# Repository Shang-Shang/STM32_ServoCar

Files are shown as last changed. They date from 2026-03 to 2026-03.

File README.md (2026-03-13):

---

# STM32_ServoCar：基于STM32与ELRS协议的智能遥控小车

<div align="center">

舵机小车-成品方案

**全流程自主开发的智能遥控小车｜从电路仿真到机械结构设计的一体化实践**



[]()

</div>

## 📋 项目概述

本项目是一个完全自主开发的智能遥控小车，旨在通过完整的硬件产品开发流程，系统性地实践嵌入式系统、电路设计和机械结构相关知识。

### 核心参数
- **主控芯片**：STM32F103C8T6
- **通信协议**：ELRS（ExpressLRS）2.4G，实现高响应遥控
- **硬件设计**：Proteus仿真验证 → Cadence/立创EDA绘制原理图与PCB → 嘉立创打样生产
- **结构设计**：SolidWorks完成整车三维建模与结构优化

### ✨ 项目亮点
- ✅ **全流程自主开发**：从电路仿真、嵌入式开发到机械结构设计，实现产品完整研发流程
- ✅ **双版本迭代优化**：V1立创EDA入门验证 → V2 Cadence专业设计，形成清晰的迭代改进路径
- ✅ **完整的文档体系**：包含采购清单、电路原理图、PCB设计文件、3D模型及源码

---

## 🔄 版本演进

本项目经历了两个主要版本的迭代：

<div align="center">
实物照片
<p><em>实物照片：第一版PCB兼容两代车架</em></p>
</div>

### 第一版：麦轮小车
- 采用四个N20减速电机，通过差速控制实现全向移动
- 使用立创EDA完成PCB设计（适合初学者快速上手）
- 验证了ELRS通信协议和基础运动控制逻辑

### 第二版：舵机转向小车
- 保留第一版PCB的兼容性，仅更换车架结构
- 采用SG90舵机实现前轮转向 + 后轮驱动
- 使用Cadence重新设计PCB，优化布局和电源保护
- SolidWorks完成整车结构优化，3D打印制作车架

---

## 📦 采购清单

| 组件 | 规格/型号 | 数量 | 备注 |
|---|---|---|---|
| ELRS接收机 | 2.4G 100mW | 1 | 串口通信 |
| 锂电池 | 7.4V 2S | 1 | 供电推荐 |
| N20减速电机 | 6V 200RPM（推荐） | 4 | 4电机驱动 |
| 轮胎 | 14mm橡胶胎 | 4 | 适配舵机版小车 |
| SG90舵机 | 9g微型舵机 | 1 | 转向机构 |
| 螺丝 | M3*10 | 若干 | 固定结构件 |
| PCB板 | 定制 | 1 | BOM表详见下方 |

> 📌 完整BOM表可在`00_BOM`文件夹中下载

---

## 💻 嵌入式开发

### 开发环境
- **IDE**：STM32CubeIDE（HAL库）
- **调试工具**：ST-Link

<div align="center">
CubeIDE配置
<p><em>STM32CubeIDE引脚功能配置</em></p>
</div>

### 代码结构

#### 舵机与电机控制 (`sk_motor.c`)
```c
void Servo_Init(void);           // 舵机初始化（PWM配置）
void Servo_Move(uint8_t CHn);    // 舵机转向控制，输入0~100（对应-90°~+90°）
void Motor_Init(void);            // 电机驱动初始化（GPIO+PWM）
void Motor_Move(uint8_t CHn, uint8_t Start);  // 电机调速，输入0~100
```

#### ELRS协议解析 (`elrs.c`)
```c
uint16_t ELRS_CRC8(uint8_t *Data);                // CRC校验（多项式0xD5，初始值0x00）
void ELRS_DataAnalysis(uint16_t *Channel, uint8_t *ReceiveData);  // 解析ELRS负载数据，提取CH1~CH10
uint16_t ELRS_ToPercentage(uint16_t CHn, uint16_t Min, uint16_t Max);  // 通道值归一化（0~100）
void ELRS_Process(uint8_t *DataA, uint8_t *CH);   // 主处理函数：原始数据输入→CH1~CH10输出（0~100）
```

<div align="center">
代码结构
<p><em>详细代码查看如上目录</em></p>
</div>

### 📡 ELRS通信协议详解

**串口配置**：
- USART1（PA9-TX, PA10-RX）
- 波特率：420Kbits
- 数据格式：8N1
- 供电：5V

**数据包结构**：

| 字节位置 | 内容 | 说明 |
|---|---|---|
| 0 | 同步字节 | 固定为`0xC8` |
| 1 | 长度 | 类型`1`+负载`22`+CRC`1`=`24`（十六进制`0x18`） |
| 2 | 类型 | 表示数据帧的类型，RC通道数据类型为`0x16` |
| 3~24 | 负载 | CH1~CH16，每个通道11bit，共176位（22字节） |
| 25 | CRC校验 | 校验范围：字节2~24 |

> CRC算法：多项式`0xD5`，初始值`0x00`，用于数据完整性验证

### 🔧 Proteus仿真

在PCB打样前，使用Proteus搭建仿真电路，验证STM32最小系统、电机驱动逻辑。

<div align="center">
Proteus仿真
<p><em>Proteus电路仿真验证</em></p>
</div>

---

## 🔌 硬件设计

### 电源功耗预算

| 组件 | 工作电压 | 典型电流 | 峰值电流 | 备注 |
|---|---|---|---|---|
| N20电机（单个） | 6V | 100mA | 200mA | 堵转电流 |
| SG90舵机 | 5V | 200mA | 500mA | 堵转电流 |
| ELRS接收机 | 5V | 20mA | 30mA | - |
| TB6612FNG（双路） | 5V | 5mA | 10mA | 逻辑部分 |
| STM32F103 | 3.3V | 50mA | 150mA | - |
| **总计** | - | **~500mA** | **~1.5A** | 按四个电机 |

### 版本V1：立创EDA入门验证

作为PCB设计的入门实践，第一版采用立创EDA完成，重点掌握原理图绘制、PCB布局布线、BOM导出和样板焊接调试。

#### 关键元件参数

| 参考文档 | 型号 | 封装 | 功能 | 关键参数 |
|-----|---|---|---|---|
| B1 | LDL1117S33R | SOT-223 | 3.3V LDO | 输入2.5-18V，输出3.3V/1.2A，压差350mV@1.2A |
| B2 | LDL1117S50R | SOT-223 | 5V LDO | 输入2.5-18V，输出5V/1.2A，压差600mV@1.2A |
| C3 | TB6612FNG | SSOP-24 | 电机驱动 | 逻辑5V，驱动15Vmax，1.2A(ave)/3.2A(peak) |

#### 设计文件

<div align="center">
V1原理图
<p><em>V1原理图（立创EDA）</em></p>
</div>

<div align="center">
V1 PCB布局
<p><em>V1 PCB布局布线</em></p>
</div>

#### BOM表

<div align="center">
V1 BOM
<p><em>V1 BOM表（可在00_BOM文件夹下载）</em></p>
</div>

#### 实物成品

<div align="center">
V1 PCB成品
<p><em>V1 PCB打样成品</em></p>
</div>

#### 版本V1经验教训

1. **布局不合理**：电机接线端口集中在单侧，导致小车走线混乱，线束整理困难
2. **缺少保护机制**：无过流/过压保护，若电源模块击穿会损坏全板
3. **踩坑教训**：采购廉价芯片导致反复排查，延误开发进度约两周

### 版本V2：Cadence专业设计

基于V1的经验教训，使用Cadence进行完全重新设计，引入更专业的EDA工具链。

#### 工具链学习
- **OrCAD Capture**：原理图设计、元器件符号绘制、网表和BOM导出
- **Padstack Editor**：焊盘和过孔定制
- **Allegro PCB Designer**：PCB布局布线、封装绘制、规则设置

#### 关键改进

1. ✅ **布局优化**：电机输出端口按实际需求调整，便于走线整理
2. ✅ **过流保护**：增加保险丝，防止电源短路损坏
3. ✅ **电源模块重构**：优化电源走线，提升接入电压上限
4. ✅ **电源开关**：增加总电源控制，方便调试

#### 新增关键元件

| 参考文档 | 型号 | 封装 | 功能 | 关键参数 |
|-----|---|---|---|---|
| B3 | MP1584EN-LF-Z | SOIC-8-EP | DCDC降压 | 输入7-28V，输出0.8-25V，3A，静态电流100uA |

#### 原理图设计

<div align="center">
V2原理图1
<p><em>V2原理图 - 设计思路</em></p>
</div>

<div align="center">
V2原理图2
<p><em>V2原理图 - MCU</em></p>
</div>

<div align="center">
V2原理图3
<p><em>V2原理图 - POWER</em></p>
</div>

<div align="center">
V2原理图4
<p><em>V2原理图 - 电机驱动</em></p>
</div>

<div align="center">
V2原理图5
<p><em>V2原理图 - 对外接口</em></p>
</div>

#### PCB设计

<div align="center">
V2 PCB顶层
<p><em>V2 PCB - 顶层布线</em></p>
</div>

<div align="center">
V2 PCB GND层
<p><em>V2 PCB - GND层</em></p>
</div>

<div align="center">
V2 PCB电源层
<p><em>V2 PCB - 电源层</em></p>
</div>

<div align="center">
V2 PCB双层视图
<p><em>V2 PCB - 底层</em></p>
</div>

#### BOM表

<div align="center">
V2 BOM
<p><em>V2 BOM表</em></p>
</div>

---

## 🏗️ 机械结构设计

### SolidWorks 3D建模

使用SolidWorks完成整车结构设计，包括底盘承载布局、舵机安装机构、电池仓设计和螺丝固定位优化。

<div align="center">
SolidWorks模型
<p><em>SolidWorks整车三维模型</em></p>
</div>

### 3D打印实现

从SolidWorks导出STL文件，导入Blender进行模型预览与颜色配置。

<div align="center">
Blender渲染
<p><em>Blender渲染效果图</em></p>
</div>

**打印参数**：
- **设备**：拓竹P1S（0.4mm喷头）
- **材料**：PLA/ PETG

**设计注意事项**：
- 打印误差补偿：PLA/PETG普遍存在0.1~0.2mm误差，设计需预留公差
- 螺丝孔优化：若需拧入M3螺丝，设计孔径**2.95mm**可获得最佳紧固效果

---

## 📚 参考目录

| 编号 | 文档名称 | 说明 |
|-----|---|---|
| 【A1】 | STM32F103x8B数据手册 | 主控芯片数据手册 |
| 【A2】 | STM32F10xxx参考手册 | 开发参考手册 |
| 【A3】 | STM32F103C8T6引脚定义 | 引脚功能定义 |
| 【B1】 | LDL1117S33R规格书 | 3.3V LDO数据手册 |
| 【B2】 | LDL1117S50R规格书 | 5V LDO数据手册 |
| 【B3】 | MP1584EN-LF-Z规格书 | DCDC电源芯片数据手册 |
| 【C3】 | TB6612FNG规格书 | 电机驱动芯片数据手册 |

---

## 📬 联系我

- **邮箱1**：1161812370@qq.com
- **邮箱2**：shang_ah@sina.com

**如果这个项目对你有帮助，欢迎Star⭐！**

---

> **项目状态**：持续完善中

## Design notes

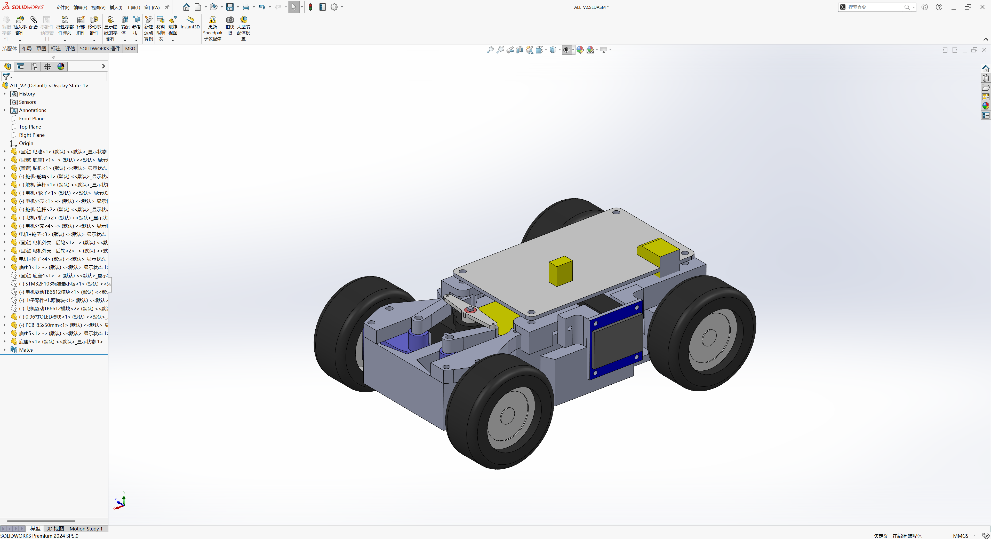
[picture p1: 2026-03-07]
04 Solidworks/舵机小车-成品方案.png

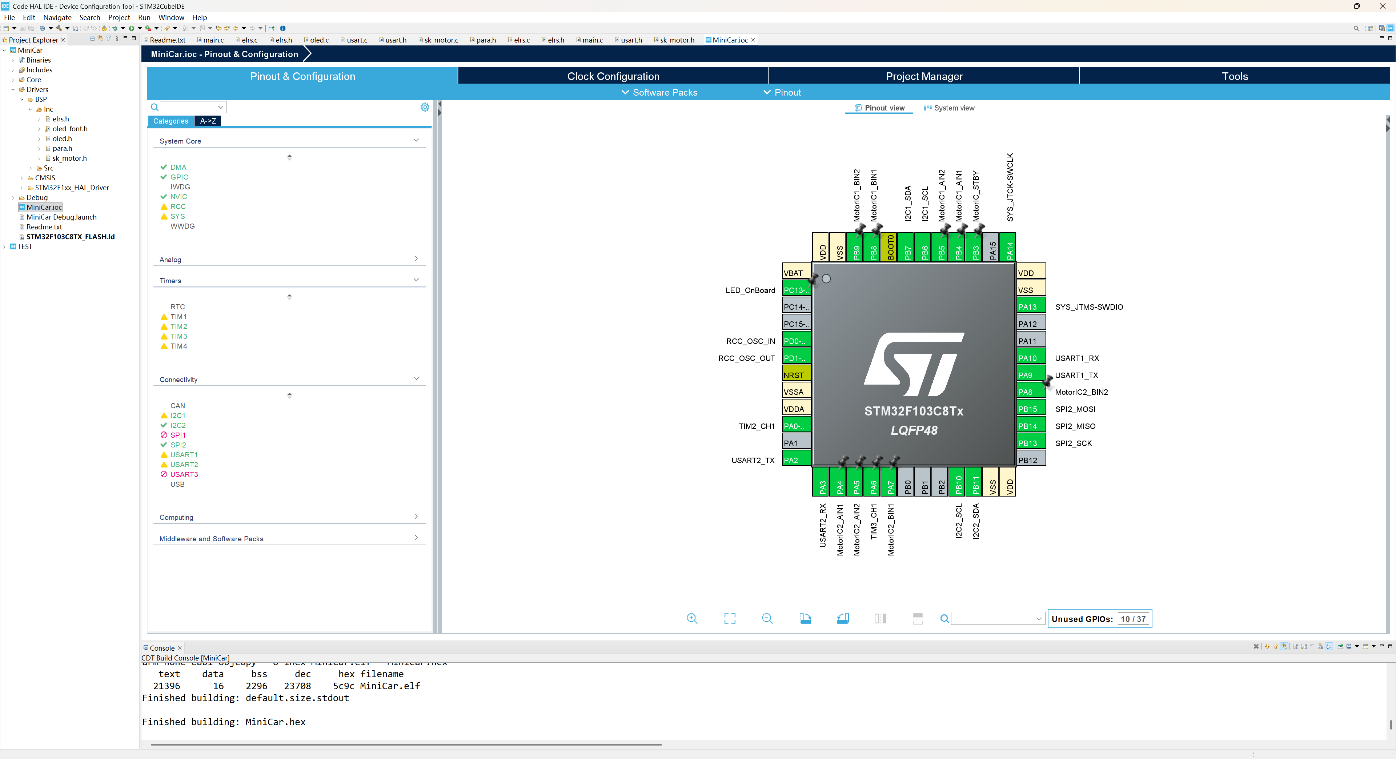
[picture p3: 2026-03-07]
02 HAL IDE/功能配置.png

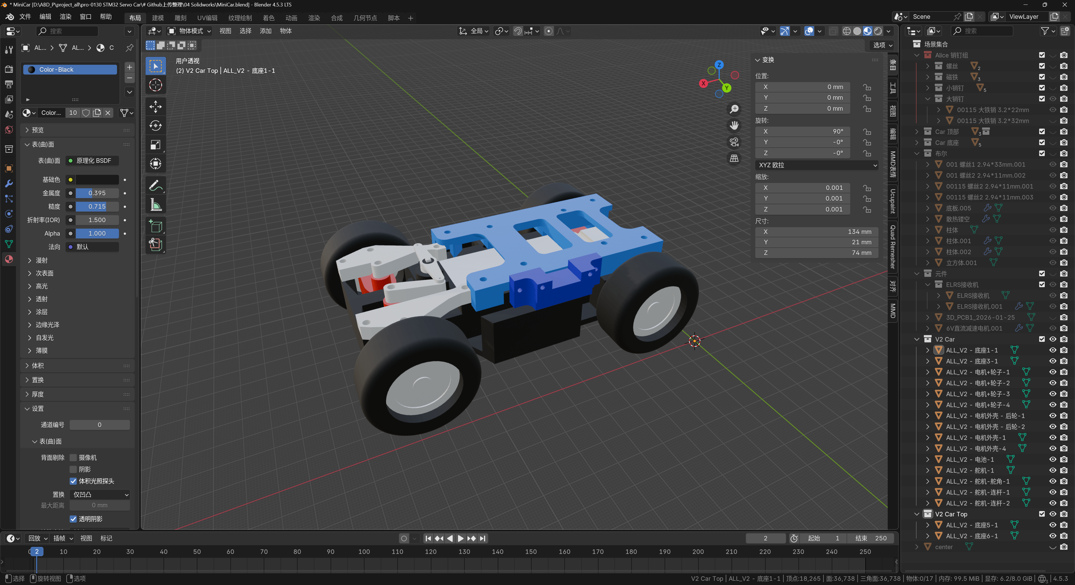
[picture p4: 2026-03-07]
04 Solidworks/舵机小车-成品渲染.png

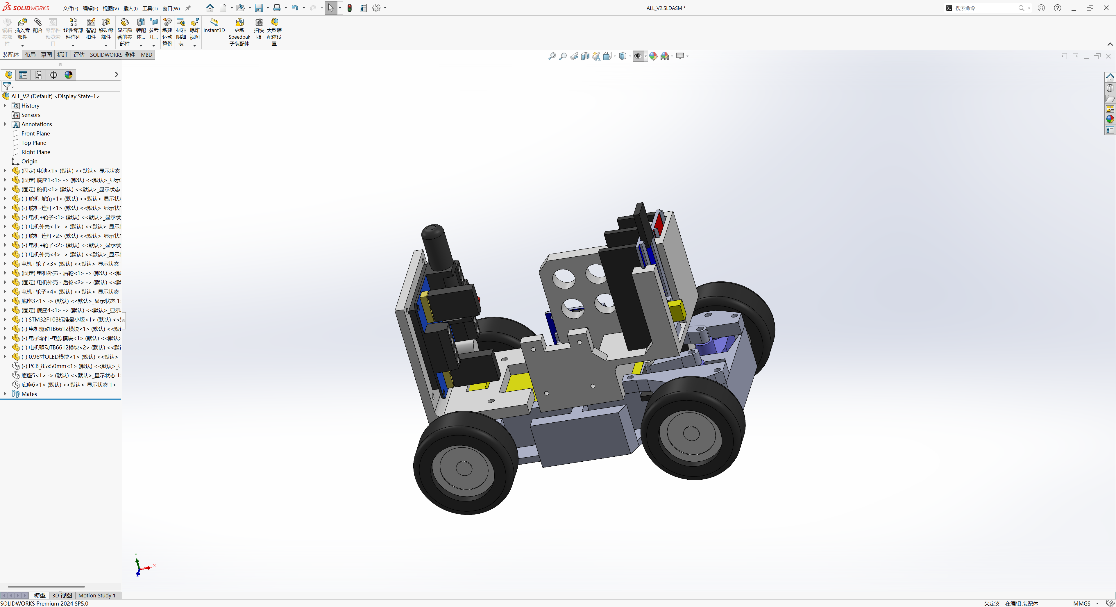
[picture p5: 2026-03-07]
04 Solidworks/舵机小车-模块验证方案.png

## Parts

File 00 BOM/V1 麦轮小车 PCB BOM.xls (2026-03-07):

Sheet: 嘉立创购买
立创商城BOM报价单
BOM配单编号：BOM260124001115 |  |  |  |  | 上传时间：2026-01-24 12:18:51 |  |  |  | 1.名称释义：MPQ--最小包装量；MOQ--最小起订量； 2.匹配结果为实时查询结果，库存和价格可能会有波动。如超过24小时，请在立创商城重新匹配后下单； 3.订货商品的价格仅供参考，请提交订单后确定。 4.如有部分物料未能成功匹配，需要整单购买，请联系商城客服。
BOM名称：pro-0120-MiniCar_PCB1_20260124_121841 |  |  |  |  | 采购套数：1
商品总价:￥84.22 (原价:￥86.69, 折扣:-￥2.47) 注：报价单总价不含待确认和无法匹配项 |  |  |  |  | 网址：https://bom.szlcsc.com/bom.html
原始需求 |  |  |  |  |  |  |  |  | 匹配结果 |  |  |  |  |  |  | 订单满足
ID | Name Manufacturer Part | Designator | Footprint | Quantity | Manufacturer Part | Manufacturer | Supplier | Supplier Part | 匹配结果 | 商品名称 | 型号 | 品牌 | 封装 | 参数 | 目录 | 商品编号 | 商品链接 | 渠道 | 交期 | MOQ | MPQ | 库存 | 购买数量 | 单价(RMB) | 关税 | 小计(RMB) | 备注
1 | PZ254V-12-6P PZ254V-12-6P | H2,H15 | HDR-TH_6P-P2.54-V-M-R2-C3-S2.54 | 2 | PZ254V-12-6P | XFCN(兴飞) | LCSC | C492420 | 系统匹配 | 2x3P 间距:2.54mm 方针 直插 | PZ254V-12-6P | XFCN(兴飞) | 插件,P=2.54mm | 插针结构：2x3P 间距：2.54mm 行距：2.54mm 圆针/方针：方针 安装方式：直插 排数：双排 总PIN位数：6P 配合针长度：6mm 塑高：2.5mm 端接针长度：3mm 触头材质：黄铜 工作温度：-40℃~+105℃ 颜色：黑色 | 连接器 | C492420 | https://item.szlcsc.com/502976.html | 现货 | 4小时内发货 | 20 | 1000 | 73260 | 20 | 0.220495 | 0 | 4.41
2 | STM32F103C8T6 STM32F103C8T6 | U1 | LQFP-48_L7.0-W7.0-P0.50-LS9.0-BL | 1 | STM32F103C8T6 | ST(意法半导体) | LCSC | C8734 | 系统匹配 | 主流增强型ARM Cortex-M3 MCU，具有64 KB Flash、72 MHz CPU、电机控制、USB和CAN | STM32F103C8T6 | ST(意法半导体) | LQFP-48(7x7) | CPU内核：ARM Cortex-M3 CPU最大主频：72MHz CPU位数：32 Bit | 单片机/微控制器 | C8734 | https://item.szlcsc.com/9243.html | 现货 | 4小时内发货 | 1 | 250 | 14564 | 1 | 7.99 | 0 | 7.99
3 | TB6612FNG,C,8,EL TB6612FNG,C,8,EL | U2,U3 | SSOP-24_L8.3-W5.6-P0.65-LS7.6-BL | 2 | TB6612FNG,C,8,EL | TOSHIBA(东芝) | LCSC | C141517 | 系统匹配 | 1A 有刷直流电机驱动芯片 5.5V | TB6612FNG,C,8,EL | TOSHIBA(东芝) | SSOP-24 |  | 电机驱动芯片 | C141517 | https://item.szlcsc.com/152848.html | 现货 | 4小时内发货 | 1 | 2000 | 3676 | 2 | 6.83 | 0 | 13.66
4 | LDL1117S33R LDL1117S33R | U4 | SOT-223-4_L6.5-W3.5-P2.30-LS7.0-BR | 1 | LDL1117S33R | ST(意法半导体) | LCSC | C435835 | 系统匹配 | 3.3V 1.2A 18V | LDL1117S33R | ST(意法半导体) | SOT-223-4 | 输出类型：固定 工作电压：18V 输出电压：3.3V 输出电流：1.2A 电源纹波抑制比(PSRR)：87dB@(120Hz) 输出极性：正极 | 电源管理 | C435835 | https://item.szlcsc.com/433206.html | 现货 | 4小时内发货 | 5 | 2500 | 8340 | 5 | 0.889 | 0 | 4.45
5 | LDL1117S50R LDL1117S50R | U5,U6,U7 | SOT-223-3_L6.5-W3.4-P2.30-LS7.0-BR | 3 | LDL1117S50R | ST(意法半导体) | LCSC | C970558 | 系统匹配 | 5V 1.2A 18V | LDL1117S50R | ST(意法半导体) | SOT-223 | 输出类型：固定 工作电压：18V 输出电压：5V 输出电流：1.2A 电源纹波抑制比(PSRR)：87dB@(120Hz) 输出极性：正极 | 电源管理 | C970558 | https://item.szlcsc.com/1060020.html | 现货 | 4小时内发货 | 5 | 2500 | 16485 | 5 | 1.8515 | 0 | 9.26
6 | MicroXNJ MicroXNJ | USB1 | MICRO-USB-SMD_MICROXNJ_1 | 1 | MicroXNJ | SHOU HAN(首韩) | LCSC | C404969 | 系统匹配 | Micro小牛角卧贴母座 | MicroXNJ | SHOU HAN(首韩) | SMD | 连接器类型：Micro-B 协议标准：USB 2.0 公母：母 安装方式：卧贴 触点数量：5P 端口数量：1 额定电流 - 电源：1.8A 工作温度：-20℃~+85℃ | 连接器 | C404969 | https://item.szlcsc.com/392534.html | 现货 | 4小时内发货 | 10 | 1000 | 162950 | 10 | 0.23275 | 0 | 2.33
7 | 8MHz X49SM8MSD2SC | X1 | CRYSTAL-SMD_L11.5-W4.8-LS12.7 | 1 | X49SM8MSD2SC | YXC(扬兴晶振) | LCSC | C12674 | 系统匹配 | HC-49SMD 8MHZ 20PF ±20PPM -20~70℃（±30PPM） | X49SM8MSD2SC | YXC(扬兴晶振) | HC-49S-SMD | 晶振类型：贴片晶振 频率：8MHz 常温频差：±20ppm 负载电容：20pF 频率稳定度：±30ppm | 振荡器/谐振器 | C12674 | https://item.szlcsc.com/13310.html | 现货 | 4小时内发货 | 5 | 1000 | 388540 | 5 | 0.5675 | 0 | 2.84
8 | 32.768kHz Y306832768KSBBX | X2 | CRYSTAL-SMD_L7.0-W3.2-LS7.5 | 1 | Y306832768KSBBX | JLYE(晶力源) | LCSC | C52205488 | 系统匹配 | Y306832768KSBBX | Y306832768KSBBX | JLYE(晶力源) | SMD,7x3.2mm | 晶振类型：贴片晶振 频率：32.768kHz 常温频差：±10ppm 负载电容：12.5pF 频率稳定度：±30ppm | 振荡器/谐振器 | C52205488 | https://item.szlcsc.com/55048192.html | 现货 | 4小时内发货 | 10 | 3000 | 330 | 10 | 0.425885 | 0 | 4.26
9 | XT30PW-M30.G.Y XT30PW-M30.G.Y | CN1 | CONN-TH_XT30PW-M | 1 | XT30PW-M30.G.Y | AMASS(艾迈斯) | LCSC | C431092 | 系统匹配 | AMASS(艾迈斯)航模插头 卧式弯脚 XT30PW-M公头 | XT30PW-M30.G.Y | AMASS(艾迈斯) | - |  | 工控电气 | C431092 | https://item.szlcsc.com/426930.html | 现货 | 4小时内发货 | 1 | 500 | 75348 | 1 | 1.85 | 0 | 1.85
10 | PZ254R-11-04P PZ254R-11-04P | H1 | HDR-TH_4P-P2.54-H-M-W10.4 | 1 | PZ254R-11-04P | XFCN(兴飞) | LCSC | C492412 | 系统匹配 | 1x4P 间距:2.54mm 方针 弯插 | PZ254R-11-04P | XFCN(兴飞) | 弯插,P=2.54mm | 插针结构：1x4P 间距：2.54mm 圆针/方针：方针 安装方式：弯插 排数：单排 总PIN位数：4P 配合针长度：6mm 塑高：2.5mm 触头材质：黄铜 工作温度：-40℃~+105℃ 颜色：黑色 | 连接器 | C492412 | https://item.szlcsc.com/502968.html | 现货 | 4小时内发货 | 20 | 1000 | 51060 | 20 | 0.16701 | 0 | 3.34
11 | PZ254V-11-04P PZ254V-11-04P | H14,H13,H11,H7,H8 | HDR-TH_4P-P2.54-V-M | 5 | PZ254V-11-04P | XFCN(兴飞) | LCSC | C492403 | 系统匹配 | 1x4P 间距:2.54mm 方针 直插 | PZ254V-11-04P | XFCN(兴飞) | 插件,P=2.54mm | 插针结构：1x4P 间距：2.54mm 圆针/方针：方针 安装方式：直插 排数：单排 总PIN位数：4P 配合针长度：6mm 塑高：2.5mm 端接针长度：3mm 触头材质：黄铜 工作温度：-40℃~+105℃ 颜色：黑色 | 连接器 | C492403 | https://item.szlcsc.com/502959.html | 现货 | 4小时内发货 | 20 | 2000 | 44320 | 20 | 0.138795 | 0 | 2.78
12 | 20pF CL10C200JB8NNNC | C1,C2,C3,C4 | C0603 | 4 | CL10C200JB8NNNC | SAMSUNG(三星) | LCSC | C1648 | 系统匹配 | 20pF ±5% 50V | CL10C200JB8NNNC | SAMSUNG(三星) | 0603 | 容值：20pF 精度：±5% 额定电压：50V 温度系数：C0G | 电容 | C1648 | https://item.szlcsc.com/2000.html | 现货 | 4小时内发货 | 100 | 4000 | 245900 | 100 | 0.0322 | 0 | 3.22
13 | 100nF CC0603KRX7R9BB104 | C5,C6,C7,C9,C11,C13,C23,C25,C27,C29 | C0603 | 10 | CC0603KRX7R9BB104 | YAGEO(国巨) | LCSC | C14663 | 系统匹配 | 100nF ±10% 50V | CC0603KRX7R9BB104 | YAGEO(国巨) | 0603 | 容值：100nF 精度：±10% 额定电压：50V 温度系数：X7R | 电容 | C14663 | https://item.szlcsc.com/15331.html | 现货 | 4小时内发货 | 100 | 4000 | 21351900 | 100 | 0.0156 | 0 | 1.56
14 | 10uF RVT16V10M4X5 | C8,C10,C12,C14 | CAP-SMD_BD4.0-L4.3-W4.3-LS5.0-FD | 4 | RVT16V10M4X5 | JIERR(捷而瑞) | LCSC | C47023101 | 系统匹配 | 10uF ±20% 16V | RVT16V10M4X5 | JIERR(捷而瑞) | SMD,D4xL5.4mm | 容值：10uF 精度：±20% 额定电压：16V 纹波电流：17mA@120Hz | 电容 | C47023101 | https://item.szlcsc.com/49206202.html | 现货 | 4小时内发货 | 20 | 2000 | 37700 | 20 | 0.1805 | 0 | 3.61
15 | 1uF CGA0603X5R105K500JT | C15,C17,C19,C21 | C0603 | 4 | CGA0603X5R105K500JT | HRE(芯声) | LCSC | C6119852 | 系统匹配 | 1uF ±10% 50V | CGA0603X5R105K500JT | HRE(芯声) | 0603 | 容值：1uF 精度：±10% 额定电压：50V 温度系数：X5R | 电容 | C6119852 | https://item.szlcsc.com/7062558.html | 现货 | 4小时内发货 | 100 | 4000 | 8066700 | 100 | 0.0282 | 0 | 2.82
16 | 4.7uF CL10A475KO8NNNC | C16,C18,C20,C22 | C0603 | 4 | CL10A475KO8NNNC | SAMSUNG(三星) | LCSC | C19666 | 系统匹配 | 4.7uF ±10% 16V | CL10A475KO8NNNC | SAMSUNG(三星) | 0603 | 容值：4.7uF 精度：±10% 额定电压：16V 温度系数：X5R | 电容 | C19666 | https://item.szlcsc.com/20375.html | 现货 | 4小时内发货 | 10 | 4000 | 6309350 | 10 | 0.0648 | 0 | 0.65
17 | 10uF CGA0603X5R106K100JT | C24,C26,C28,C30 | C0603 | 4 | CGA0603X5R106K100JT | HRE(芯声) | LCSC | C6119842 | 系统匹配 | 10uF ±10% 10V | CGA0603X5R106K100JT | HRE(芯声) | 0603 | 容值：10uF 精度：±10% 额定电压：10V 温度系数：X5R | 电容 | C6119842 | https://item.szlcsc.com/7062548.html | 现货 | 4小时内发货 | 100 | 4000 | 3475900 | 100 | 0.0406 | 0 | 4.06
18 | B-2100S02P-A110 B-2100S02P-A110 | H3,H4,H5,H6,H9,H10 | HDR-TH_2P-P2.54-V-M-1 | 6 | B-2100S02P-A110 | Ckmtw(灿科盟) | LCSC | C124375 | 系统匹配 | 2.54直排针 | B-2100S02P-A110 | Ckmtw(灿科盟) | 插件,P=2.54mm | 插针结构：1x2P 间距：2.54mm 安装方式：直插 排数：单排 总PIN位数：2P 配合针长度：6mm 塑高：2.54mm 端接针长度：3mm 触头材质：黄铜 工作温度：-40℃~+105℃ 颜色：黑色 | 连接器 | C124375 | https://item.szlcsc.com/125650.html | 现货 | 4小时内发货 | 20 | 5000 | 132920 | 20 | 0.15903 | 0 | 3.18
19 | PZ254V-11-07P PZ254V-11-07P | H12 | HDR-TH_7P-P2.54-V-M | 1 | PZ254V-11-07P | XFCN(兴飞) | LCSC | C492406 | 系统匹配 | 1x7P 间距:2.54mm 方针 直插 | PZ254V-11-07P | XFCN(兴飞) | 插件,P=2.54mm | 插针结构：1x7P 间距：2.54mm 圆针/方针：方针 安装方式：直插 排数：单排 总PIN位数：7P 配合针长度：6mm 塑高：2.5mm 端接针长度：3mm 触头材质：黄铜 工作温度：-40℃~+105℃ 颜色：黑色 | 连接器 | C492406 | https://item.szlcsc.com/502962.html | 现货 | 4小时内发货 | 10 | 1000 | 5490 | 10 | 0.23826 | 0 | 2.38
20 | NCD0603Y2 NCD0603Y2 | LED1,LED2 | LED0603-RD | 2 | NCD0603Y2 | 国星光电 | LCSC | C89811 | 系统匹配 | 片式发光二极管 | NCD0603Y2 | 国星光电 | 0603 | 发光颜色：黄色 正向压降(Vf)：1.6V~2.6V 功率：65mW 正向电流：25mA 波长：586nm~595nm 二极管配置：独立二极管 发光强度：220mcd 发光角度：130° 工作温度：-30℃~+85℃ | 光电器件 | C89811 | https://item.szlcsc.com/90993.html | 现货 | 4小时内发货 | 20 | 4000 | 192420 | 20 | 0.1138 | 0 | 2.28
21 | 1MΩ 0603WAF1004T5E | R1 | R0603 | 1 | 0603WAF1004T5E | UNI-ROYAL(厚声) | LCSC | C22935 | 系统匹配 | 1MΩ ±1% 100mW 厚膜电阻 | 0603WAF1004T5E | UNI-ROYAL(厚声) | 0603 | 电阻类型：厚膜电阻 阻值：1MΩ 精度：±1% 功率：100mW 工作电压：75V 温度系数：±100ppm/℃ | 电阻 | C22935 | https://item.szlcsc.com/23662.html | 现货 | 4小时内发货 | 100 | 5000 | 642800 | 100 | 0.006365 | 0 | 0.64
22 | 10kΩ 0603WAF1002T5E | R2,R3 | R0603 | 2 | 0603WAF1002T5E | UNI-ROYAL(厚声) | LCSC | C25804 | 系统匹配 | 厚膜电阻 10kΩ ±1% 100mW | 0603WAF1002T5E | UNI-ROYAL(厚声) | 0603 | 电阻类型：厚膜电阻 阻值：10kΩ 精度：±1% 功率：100mW 工作电压：75V 温度系数：±100ppm/℃ | 电阻 | C25804 | https://item.szlcsc.com/26547.html | 现货 | 4小时内发货 | 100 | 5000 | 38174800 | 100 | 0.00627 | 0 | 0.63
23 | 510Ω 0603WAF5100T5E | R4,R5 | R0603 | 2 | 0603WAF5100T5E | UNI-ROYAL(厚声) | LCSC | C23193 | 系统匹配 | 510Ω ±1% 100mW 厚膜电阻 | 0603WAF5100T5E | UNI-ROYAL(厚声) | 0603 | 电阻类型：厚膜电阻 阻值：510Ω 精度：±1% 功率：100mW 工作电压：75V 温度系数：±100ppm/℃ | 电阻 | C23193 | https://item.szlcsc.com/23920.html | 现货 | 4小时内发货 | 100 | 5000 | 1695300 | 100 | 0.00627 | 0 | 0.63
24 | 20Ω 0603WAF200JT5E | R6,R7 | R0603 | 2 | 0603WAF200JT5E | UNI-ROYAL(厚声) | LCSC | C22950 | 系统匹配 | 20Ω ±1% 100mW 厚膜电阻 | 0603WAF200JT5E | UNI-ROYAL(厚声) | 0603 | 电阻类型：厚膜电阻 阻值：20Ω 精度：±1% 功率：100mW 工作电压：75V 温度系数：±100ppm/℃ | 电阻 | C22950 | https://item.szlcsc.com/23677.html | 现货 | 4小时内发货 | 100 | 5000 | 806000 | 100 | 0.006745 | 0 | 0.67
25 | 4.7kΩ RC0603FR-074K7L | R8 | R0603 | 1 | RC0603FR-074K7L | YAGEO(国巨) | LCSC | C99782 | 系统匹配 | 厚膜电阻 4.7kΩ ±1% 100mW | RC0603FR-074K7L | YAGEO(国巨) | 0603 | 电阻类型：厚膜电阻 阻值：4.7kΩ 精度：±1% 功率：100mW 工作电压：75V 温度系数：±100ppm/℃ | 电阻 | C99782 | https://item.szlcsc.com/100996.html | 现货 | 4小时内发货 | 100 | 5000 | 2832300 | 100 | 0.0079 | 0 | 0.79
26 | HX 3x4x2-2P-2.5N HX 3x4x2-2P-2.5N | SW1 | SW-SMD_L4.0-W2.9-LS5.0 | 1 | HX 3x4x2-2P-2.5N | hanxia(韩下) | LCSC | C36498961 | 系统匹配 | 4*3*2mm 立贴 轻触开关 | HX 3x4x2-2P-2.5N | hanxia(韩下) | SMD,4x3mm | 电路结构：单刀单掷 按钮形状：圆形按钮 作用力：2.5N 安装方式：立贴 开关长度：4mm 开关宽度：3mm 开关高度：2mm 带支架：不带支架 触点电流：50mA 额定电压：12V 带灯：无 工作寿命：10万次 | 按键/开关 | C36498961 | https://item.szlcsc.com/38220903.html | 现货 | 4小时内发货 | 5 | 3000 | 44780 | 5 | 0.16929 | 0 | 0.85
 |  |  |  |  |  |  |  |  |  |  |  |  |  |  |  |  |  |  |  |  |  |  |  |  | 快递费 | 15.00
 |  |  |  |  |  |  |  |  |  |  |  |  |  |  |  |  |  |  |  |  |  |  |  |  |  | 100.14

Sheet: 淘宝购买
ID | Name Manufacturer Part | Designator | Footprint | Quantity | Manufacturer Part | Manufacturer | Supplier | Supplier Part | 匹配结果 | 商品名称 | 型号 | 品牌 | 封装 | 参数 | 目录 | 购买数量 | 单价(RMB) | 小计(RMB) | 备注
26 | HX 3x4x2-2P-2.5N HX 3x4x2-2P-2.5N | SW1 | SW-SMD_L4.0-W2.9-LS5.0 | 1 | HX 3x4x2-2P-2.5N | hanxia(韩下) | LCSC | C36498961 | 系统匹配 | 4*3*2mm 立贴 轻触开关 | HX 3x4x2-2P-2.5N | hanxia(韩下) | SMD,4x3mm | 电路结构：单刀单掷 按钮形状：圆形按钮 作用力：2.5N 安装方式：立贴 开关长度：4mm 开关宽度：3mm 开关高度：2mm 带支架：不带支架 触点电流：50mA 额定电压：12V 带灯：无 工作寿命：10万次 | 按键/开关 | 20 | 0.101 | 2.02
2 | STM32F103C8T6 STM32F103C8T6 | U1 | LQFP-48_L7.0-W7.0-P0.50-LS9.0-BL | 1 | STM32F103C8T6 | ST(意法半导体) | LCSC | C8734 | 系统匹配 | 主流增强型ARM Cortex-M3 MCU，具有64 KB Flash、72 MHz CPU、电机控制、USB和CAN | STM32F103C8T6 | ST(意法半导体) | LQFP-48(7x7) | CPU内核：ARM Cortex-M3 CPU最大主频：72MHz CPU位数：32 Bit | 单片机/微控制器 | 2 | 1.05 | 2.10
3 | TB6612FNG,C,8,EL TB6612FNG,C,8,EL | U2,U3 | SSOP-24_L8.3-W5.6-P0.65-LS7.6-BL | 2 | TB6612FNG,C,8,EL | TOSHIBA(东芝) | LCSC | C141517 | 系统匹配 | 1A 有刷直流电机驱动芯片 5.5V | TB6612FNG,C,8,EL | TOSHIBA(东芝) | SSOP-24 |  | 电机驱动芯片 | 4 | 1.05 | 4.20
12 | 20pF CL10C200JB8NNNC | C1,C2,C3,C4 | C0603 | 4 | CL10C200JB8NNNC | SAMSUNG(三星) | LCSC | C1648 | 系统匹配 | 20pF ±5% 50V | CL10C200JB8NNNC | SAMSUNG(三星) | 0603 | 容值：20pF 精度：±5% 额定电压：50V 温度系数：C0G | 电容 | 50 | 0.044 | 2.20
13 | 100nF CC0603KRX7R9BB104 | C5,C6,C7,C9,C11,C13,C23,C25,C27,C29 | C0603 | 10 | CC0603KRX7R9BB104 | YAGEO(国巨) | LCSC | C14663 | 系统匹配 | 100nF ±10% 50V | CC0603KRX7R9BB104 | YAGEO(国巨) | 0603 | 容值：100nF 精度：±10% 额定电压：50V 温度系数：X7R | 电容 | 50 | 0.033 | 1.65
14 | 10uF RVT16V10M4X5 | C8,C10,C12,C14 | CAP-SMD_BD4.0-L4.3-W4.3-LS5.0-FD | 4 | RVT16V10M4X5 | JIERR(捷而瑞) | LCSC | C47023101 | 系统匹配 | 10uF ±20% 16V | RVT16V10M4X5 | JIERR(捷而瑞) | SMD,D4xL5.4mm | 容值：10uF 精度：±20% 额定电压：16V 纹波电流：17mA@120Hz | 电容 | 20 | 0.12 | 2.40
15 | 1uF CGA0603X5R105K500JT | C15,C17,C19,C21 | C0603 | 4 | CGA0603X5R105K500JT | HRE(芯声) | LCSC | C6119852 | 系统匹配 | 1uF ±10% 50V | CGA0603X5R105K500JT | HRE(芯声) | 0603 | 容值：1uF 精度：±10% 额定电压：50V 温度系数：X5R | 电容 | 50 | 0.033 | 1.65
16 | 4.7uF CL10A475KO8NNNC | C16,C18,C20,C22 | C0603 | 4 | CL10A475KO8NNNC | SAMSUNG(三星) | LCSC | C19666 | 系统匹配 | 4.7uF ±10% 16V | CL10A475KO8NNNC | SAMSUNG(三星) | 0603 | 容值：4.7uF 精度：±10% 额定电压：16V 温度系数：X5R | 电容 | 50 | 0.044 | 2.20
17 | 10uF CGA0603X5R106K100JT | C24,C26,C28,C30 | C0603 | 4 | CGA0603X5R106K100JT | HRE(芯声) | LCSC | C6119842 | 系统匹配 | 10uF ±10% 10V | CGA0603X5R106K100JT | HRE(芯声) | 0603 | 容值：10uF 精度：±10% 额定电压：10V 温度系数：X5R | 电容 | 50 | 0.044 | 2.20
4 | LDL1117S33R LDL1117S33R | U4 | SOT-223-4_L6.5-W3.5-P2.30-LS7.0-BR | 1 | LDL1117S33R | ST(意法半导体) | LCSC | C435835 | 系统匹配 | 3.3V 1.2A 18V | LDL1117S33R | ST(意法半导体) | SOT-223-4 | 输出类型：固定 工作电压：18V 输出电压：3.3V 输出电流：1.2A 电源纹波抑制比(PSRR)：87dB@(120Hz) 输出极性：正极 | 电源管理 | 5 | 0.49 | 2.45
5 | LDL1117S50R LDL1117S50R | U5,U6,U7 | SOT-223-3_L6.5-W3.4-P2.30-LS7.0-BR | 3 | LDL1117S50R | ST(意法半导体) | LCSC | C970558 | 系统匹配 | 5V 1.2A 18V | LDL1117S50R | ST(意法半导体) | SOT-223 | 输出类型：固定 工作电压：18V 输出电压：5V 输出电流：1.2A 电源纹波抑制比(PSRR)：87dB@(120Hz) 输出极性：正极 | 电源管理 | 5 | 1.05 | 5.25
21 | 1MΩ 0603WAF1004T5E | R1 | R0603 | 1 | 0603WAF1004T5E | UNI-ROYAL(厚声) | LCSC | C22935 | 系统匹配 | 1MΩ ±1% 100mW 厚膜电阻 | 0603WAF1004T5E | UNI-ROYAL(厚声) | 0603 | 电阻类型：厚膜电阻 阻值：1MΩ 精度：±1% 功率：100mW 工作电压：75V 温度系数：±100ppm/℃ | 电阻 | 100 | 0.0198 | 1.98
22 | 10kΩ 0603WAF1002T5E | R2,R3 | R0603 | 2 | 0603WAF1002T5E | UNI-ROYAL(厚声) | LCSC | C25804 | 系统匹配 | 厚膜电阻 10kΩ ±1% 100mW | 0603WAF1002T5E | UNI-ROYAL(厚声) | 0603 | 电阻类型：厚膜电阻 阻值：10kΩ 精度：±1% 功率：100mW 工作电压：75V 温度系数：±100ppm/℃ | 电阻 | 100 | 0.0198 | 1.98
23 | 510Ω 0603WAF5100T5E | R4,R5 | R0603 | 2 | 0603WAF5100T5E | UNI-ROYAL(厚声) | LCSC | C23193 | 系统匹配 | 510Ω ±1% 100mW 厚膜电阻 | 0603WAF5100T5E | UNI-ROYAL(厚声) | 0603 | 电阻类型：厚膜电阻 阻值：510Ω 精度：±1% 功率：100mW 工作电压：75V 温度系数：±100ppm/℃ | 电阻 | 100 | 0.0198 | 1.98
24 | 20Ω 0603WAF200JT5E | R6,R7 | R0603 | 2 | 0603WAF200JT5E | UNI-ROYAL(厚声) | LCSC | C22950 | 系统匹配 | 20Ω ±1% 100mW 厚膜电阻 | 0603WAF200JT5E | UNI-ROYAL(厚声) | 0603 | 电阻类型：厚膜电阻 阻值：20Ω 精度：±1% 功率：100mW 工作电压：75V 温度系数：±100ppm/℃ | 电阻 | 100 | 0.0198 | 1.98
25 | 4.7kΩ RC0603FR-074K7L | R8 | R0603 | 1 | RC0603FR-074K7L | YAGEO(国巨) | LCSC | C99782 | 系统匹配 | 厚膜电阻 4.7kΩ ±1% 100mW | RC0603FR-074K7L | YAGEO(国巨) | 0603 | 电阻类型：厚膜电阻 阻值：4.7kΩ 精度：±1% 功率：100mW 工作电压：75V 温度系数：±100ppm/℃ | 电阻 | 100 | 0.0198 | 1.98
9 | XT30PW-M30.G.Y XT30PW-M30.G.Y | CN1 | CONN-TH_XT30PW-M | 1 | XT30PW-M30.G.Y | AMASS(艾迈斯) | LCSC | C431092 | 系统匹配 | AMASS(艾迈斯)航模插头 卧式弯脚 XT30PW-M公头 | XT30PW-M30.G.Y | AMASS(艾迈斯) | - |  | 工控电气 | 1 | 2.47 | 2.47
20 | NCD0603Y2 NCD0603Y2 | LED1,LED2 | LED0603-RD | 2 | NCD0603Y2 | 国星光电 | LCSC | C89811 | 系统匹配 | 片式发光二极管 | NCD0603Y2 | 国星光电 | 0603 | 发光颜色：黄色 正向压降(Vf)：1.6V~2.6V 功率：65mW 正向电流：25mA 波长：586nm~595nm 二极管配置：独立二极管 发光强度：220mcd 发光角度：130° 工作温度：-30℃~+85℃ | 光电器件 | 50 | 0.04 | 2.00
1 | PZ254V-12-6P PZ254V-12-6P | H2,H15 | HDR-TH_6P-P2.54-V-M-R2-C3-S2.54 | 2 | PZ254V-12-6P | XFCN(兴飞) | LCSC | C492420 | 系统匹配 | 2x3P 间距:2.54mm 方针 直插 | PZ254V-12-6P | XFCN(兴飞) | 插件,P=2.54mm | 插针结构：2x3P 间距：2.54mm 行距：2.54mm 圆针/方针：方针 安装方式：直插 排数：双排 总PIN位数：6P 配合针长度：6mm 塑高：2.5mm 端接针长度：3mm 触头材质：黄铜 工作温度：-40℃~+105℃ 颜色：黑色 | 连接器 | 10 | 0.066 | 0.66
6 | MicroXNJ MicroXNJ | USB1 | MICRO-USB-SMD_MICROXNJ_1 | 1 | MicroXNJ | SHOU HAN(首韩) | LCSC | C404969 | 系统匹配 | Micro小牛角卧贴母座 | MicroXNJ | SHOU HAN(首韩) | SMD | 连接器类型：Micro-B 协议标准：USB 2.0 公母：母 安装方式：卧贴 触点数量：5P 端口数量：1 额定电流 - 电源：1.8A 工作温度：-20℃~+85℃ | 连接器 | 3 | 0.19 | 0.57
10 | PZ254R-11-04P PZ254R-11-04P | H1 | HDR-TH_4P-P2.54-H-M-W10.4 | 1 | PZ254R-11-04P | XFCN(兴飞) | LCSC | C492412 | 系统匹配 | 1x4P 间距:2.54mm 方针 弯插 | PZ254R-11-04P | XFCN(兴飞) | 弯插,P=2.54mm | 插针结构：1x4P 间距：2.54mm 圆针/方针：方针 安装方式：弯插 排数：单排 总PIN位数：4P 配合针长度：6mm 塑高：2.5mm 触头材质：黄铜 工作温度：-40℃~+105℃ 颜色：黑色 | 连接器 | 10 | 0.053 | 0.53
11 | PZ254V-11-04P PZ254V-11-04P | H14,H13,H11,H7,H8 | HDR-TH_4P-P2.54-V-M | 5 | PZ254V-11-04P | XFCN(兴飞) | LCSC | C492403 | 系统匹配 | 1x4P 间距:2.54mm 方针 直插 | PZ254V-11-04P | XFCN(兴飞) | 插件,P=2.54mm | 插针结构：1x4P 间距：2.54mm 圆针/方针：方针 安装方式：直插 排数：单排 总PIN位数：4P 配合针长度：6mm 塑高：2.5mm 端接针长度：3mm 触头材质：黄铜 工作温度：-40℃~+105℃ 颜色：黑色 | 连接器 | 10 | 0.04 | 0.40
18 | B-2100S02P-A110 B-2100S02P-A110 | H3,H4,H5,H6,H9,H10 | HDR-TH_2P-P2.54-V-M-1 | 6 | B-2100S02P-A110 | Ckmtw(灿科盟) | LCSC | C124375 | 系统匹配 | 2.54直排针 | B-2100S02P-A110 | Ckmtw(灿科盟) | 插件,P=2.54mm | 插针结构：1x2P 间距：2.54mm 安装方式：直插 排数：单排 总PIN位数：2P 配合针长度：6mm 塑高：2.54mm 端接针长度：3mm 触头材质：黄铜 工作温度：-40℃~+105℃ 颜色：黑色 | 连接器 | 10 | 0.026 | 0.26
19 | PZ254V-11-07P PZ254V-11-07P | H12 | HDR-TH_7P-P2.54-V-M | 1 | PZ254V-11-07P | XFCN(兴飞) | LCSC | C492406 | 系统匹配 | 1x7P 间距:2.54mm 方针 直插 | PZ254V-11-07P | XFCN(兴飞) | 插件,P=2.54mm | 插针结构：1x7P 间距：2.54mm 圆针/方针：方针 安装方式：直插 排数：单排 总PIN位数：7P 配合针长度：6mm 塑高：2.5mm 端接针长度：3mm 触头材质：黄铜 工作温度：-40℃~+105℃ 颜色：黑色 | 连接器 | 10 | 0.066 | 0.66
7 | 8MHz X49SM8MSD2SC | X1 | CRYSTAL-SMD_L11.5-W4.8-LS12.7 | 1 | X49SM8MSD2SC | YXC(扬兴晶振) | LCSC | C12674 | 系统匹配 | HC-49SMD 8MHZ 20PF ±20PPM -20~70℃（±30PPM） | X49SM8MSD2SC | YXC(扬兴晶振) | HC-49S-SMD | 晶振类型：贴片晶振 频率：8MHz 常温频差：±20ppm 负载电容：20pF 频率稳定度：±30ppm | 振荡器/谐振器 | 2 | 0.36 | 0.72
8 | 32.768kHz Y306832768KSBBX | X2 | CRYSTAL-SMD_L7.0-W3.2-LS7.5 | 1 | Y306832768KSBBX | JLYE(晶力源) | LCSC | C52205488 | 系统匹配 | Y306832768KSBBX | Y306832768KSBBX | JLYE(晶力源) | SMD,7x3.2mm | 晶振类型：贴片晶振 频率：32.768kHz 常温频差：±10ppm 负载电容：12.5pF 频率稳定度：±30ppm | 振荡器/谐振器 | 5 | 0.17 | 0.85
 |  |  |  |  |  |  |  |  |  |  |  |  |  |  |  |  | 快递费 | 3.5
 |  |  |  |  |  |  |  |  |  |  |  |  |  |  |  |  |  | 50.84

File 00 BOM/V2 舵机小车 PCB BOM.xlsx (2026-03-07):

Item | Qty. | Parts Num. | Parts Value | FootPrint | 商品名称 | 品牌 | 商品封装 | 需求数量 | 购买数量 | 单价 | 预期成本 | 备注
1 | 5 | C1,C2,C3,C4,C15 | 22pF,16V | C0603 | 20pF ±5% 50V C0G | 三星 | 0603 | 5 | 0 | 0.044 | 0 | 有库存
2 | 2 | C5,C18 | 4.7uF,16V | C0603 | 4.7uF ±10% 16V X5R | 三星 | 0603 | 2 | 0 | 0.044 | 0 | 有库存
3 | 14 | C6,C7,C8,C11,C12,C20,C21,C24,C25,C28,C29,C30,C31,C32 | 100nF,16V | C0603 | 100nF ±10% 50V X7R | 三星 | 0603 | 14 | 0 | 0.033 | 0 | 有库存
4 | 1 | C9 | 10nF,16V | C0603 | 10nF ±5% 50V X7R | 三星 | 0603 | 1 | 100 | 0.022 | 2.2
5 | 2 | C10,C19 | 1uF,10V | C0603 | 1uF ±10% 10V X5R | 三星 | 0603 | 2 | 0 | 0.033 | 0 | 有库存
6 | 1 | C13 | 220uF,50V | CP_D10xL10R2 | 220uF ±20% 50V，贴片铝电解电容 | * | SMD10*10.2mm | 1 | 2 | 0.5 | 1
7 | 1 | C14 | 10uF,50V | C0603 | 10uF ±20% 25V X5R | 三星 | 0603 | 1 | 100 | 0.0495 | 4.95
8 | 1 | C16 | 220uF,16V | CP_D10xL10R2 | 220uF ±20% 50V，贴片铝电解电容 | * | SMD10*10.2mm | 1 | 3 | 0.5 | 1.5
9 | 1 | C17 | 150pF,16V | C0603 | 150pF ±5% 50V C0G | 三星 | 0603 | 1 | 100 | 0.022 | 2.2
10 | 4 | C22,C23,C26,C27 | 10uF,16V | CP_D4xL54 | 10uF ±20% 16V，贴片铝电解电容 | * | SMD4*5.4mm | 4 | 0 | 0.12 | 0 | 有库存
11 | 2 | D1,D2 | LED | LED0603 | 红色LED 0603 2.2V 20mA 色温620~625 | * | 0603 | 2 | 0 | 0.04 | 0 | 有库存
12 | 1 | D3 | SS34 | DO214AB | SS34C 3A 40V |  | DP214AB | 1 | 5 | 0.44 | 2.2
13 | 1 | F1 | FUSE 3A | SMD1812 | 1812 自恢复保险丝 贴片 3A 16V | * | 1812 | 1 | 5 | 0.7 | 3.5
14 | 12 | J1,J3,J4,J5,J6,J7,J12,J13,J14,J15,J16,J17 | HDR_4P | HDR4_P254 | 1x4P 间距:2.54mm 方针 直插 | 兴飞 | 插件,P=2.54mm | 12 | 0 | 0.04 | 0 | 有库存
15 | 1 | J2 | HDR_2x3P | HDR3x2_P254 | 2x3P 间距:2.54mm 方针 直插 | 兴飞 | 插件,P=2.54mm | 1 | 0 | 0.066 | 0 | 有库存
16 | 4 | J8,J9,J10,J11 | HDR_2P | HDR2_P254 | 1x2P 间距:2.54mm 方针 直插 | 兴飞 | 插件,P=2.54mm | 4 | 0 | 0.026 | 0 | 有库存
17 | 1 | L1 | 10uH,3A | H0630 | 10uH 贴片 功率电感 DCR62mΩ Irms3.5A Isat5.5A | * | 6030 | 1 | 5 | 0.54 | 2.7
18 | 2 | R1,R2 | 10K | R0603 | 10kΩ ±1% 100mW 75V ±100ppm/℃ | 国巨 | 0603 | 2 | 0 | 0.0198 | 0 | 有库存
19 | 2 | R3,R4 | 510R | R0603 | 510Ω ±1% 100mW 75V ±100ppm/℃ | 国巨 | 0603 | 2 | 0 | 0.0198 | 0 | 有库存
20 | 4 | R5,R6,R7,R9 | 100K | R0603 | 100kΩ ±1% 100mW 75V ±100ppm/℃ | 国巨 | 0603 | 4 | 100 | 0.0198 | 1.98
21 | 1 | R8 | 210K,1% | R0603 | 200kΩ ±1% 100mW 75V ±100ppm/℃ | 国巨 | 0603 | 1 | 100 | 0.0198 | 1.98
 |  |  |  |  | 10kΩ ±1% 100mW 75V ±100ppm/℃ | 国巨 | 0603 | 1 | 0 | 0.0198 | 0 | 有库存
22 | 1 | R10 | 40R2K 1% | R0603 | 39kΩ ±1% 100mW 75V ±100ppm/℃ | 国巨 | 0603 | 1 | 100 | 0.0198 | 1.98
 |  |  |  |  | 1.2kΩ ±1% 100mW 75V ±100ppm/℃ | 国巨 | 0603 | 1 | 100 | 0.0198 | 1.98
23 | 1 | SW1 | SW_PB_SPST | SW_PB_4x3 | 3*4mm微动 贴片开关 | * | 矩形 3*4mm | 1 | 0 | 0.1135 | 0 | 有库存
24 | 1 | SW2 | KCD11-2P | KCD11-2P | KCD11_2脚2挡_红色 3A 250V AC 绝缘电阻>100MΩ 接触电阻＜50mΩ | * | 矩形 15*10.5mm | 1 | 4 | 0.27 | 1.08
25 | 1 | U1 | STM32F103C8T6 | LQFP_48 | MCU STM32F103C8T6 | ST(意法半导体) | LQFP-48 | 1 | 0 | 6.2 | 0 | 有库存
26 | 1 | U2 | XT30 | XT30 | XT30PW-M 公头 板载卧式 | * | XT30卧式 | 1 | 0 | 1.43 | 0 | 有库存
27 | 1 | U3 | MP1584EN | SOIC-8-EP | MP1584EN-LF-Z 开关稳压器 3A 1.5MHz 28V | MPS | SOIC-8-EP | 1 | 2 | 6 | 12
28 | 1 | U4 | LDL1117_33R | SOT223 | LDL1117S33R 输出类型：固定 工作电压：18V 输出电压：3.3V 输出电流：1.2A 电源纹波抑制比(PSRR)：87dB@(120Hz) 输出极性：正极 | ST(意法半导体) | SOT-223 | 1 | 0 | 0.83 | 0 | 有库存
29 | 2 | U5,U6 | TB6612FNG | SSOP24 | TB6612FNG,C,8,EL | 东芝 | SSOP-24 | 2 | 0 | 4.9 | 0 | 有库存
30 | 1 | Y1 | 32.768kHz | SMD_32KHz | 无源石英晶振 8MHz 频率准确度 ±30ppm 负载电容12.5pF | * | M49SMD | 1 | 0 | 0.17 | 0 | 有库存
31 | 1 | Y2 | 8MHz | SMD_8MHz | 无源石英晶振 32.768KHz 温度频差±300ppm 频率准确度 ±10ppm 负载电容20pF | * | HC-49SMD | 1 | 0 | 0.38 | 0 | 有库存
 |  |  |  |  |  |  |  |  |  | 嘉立创打样 | 0 | 有券
 |  |  |  |  |  |  |  |  |  | 预期成本 | 41.25

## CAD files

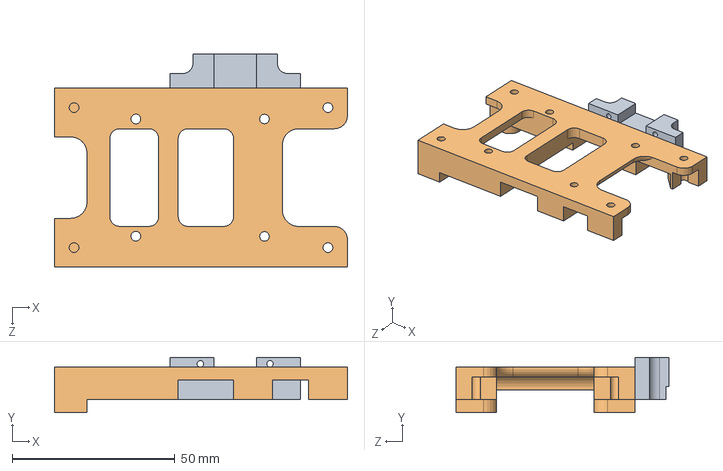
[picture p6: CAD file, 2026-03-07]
04 Solidworks/ALL_V2.SLDASM
90.0 x 17.0 x 65.5 mm
底座5
底座6

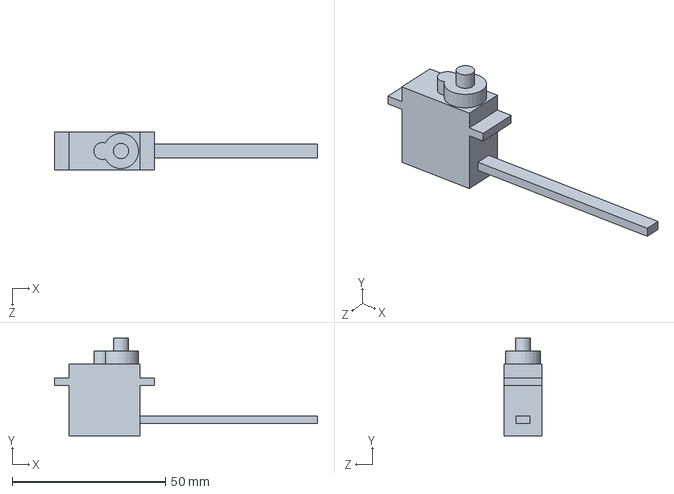
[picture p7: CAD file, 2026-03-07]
04 Solidworks/舵机.SLDPRT
85.8 x 31.9 x 12.3 mm

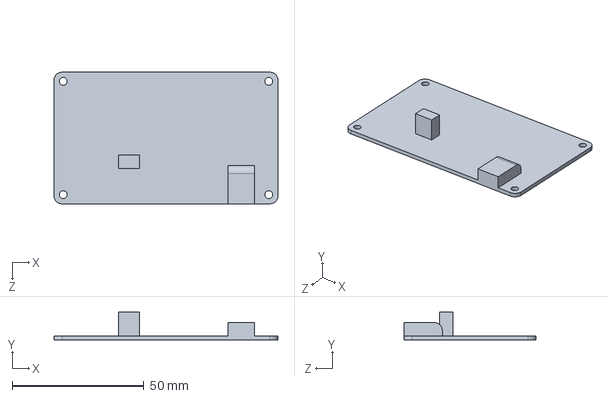
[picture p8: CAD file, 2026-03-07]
04 Solidworks/PCB_85x50mm.SLDPRT
85.0 x 10.6 x 50.0 mm

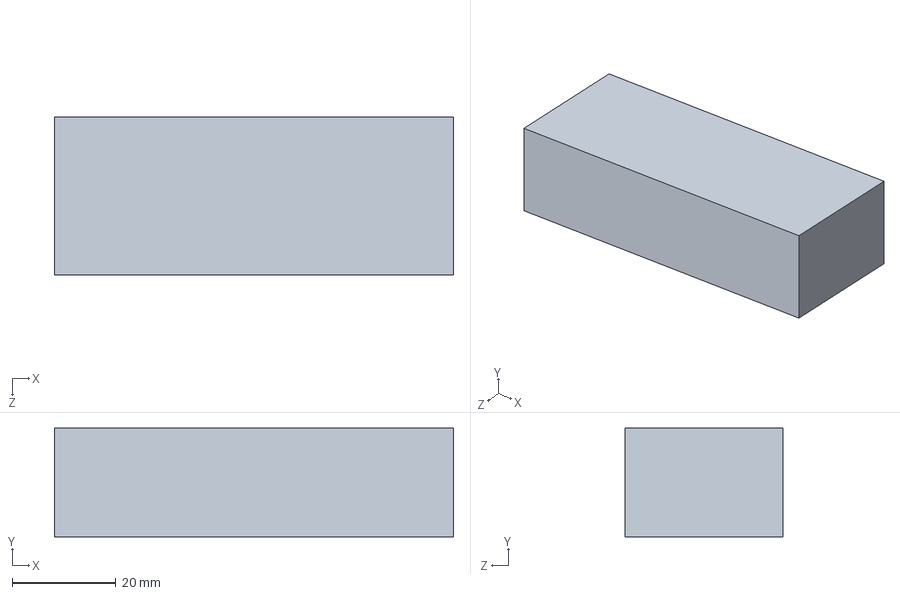
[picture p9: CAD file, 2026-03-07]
04 Solidworks/电池2.SLDPRT
77.0 x 21.0 x 30.5 mm

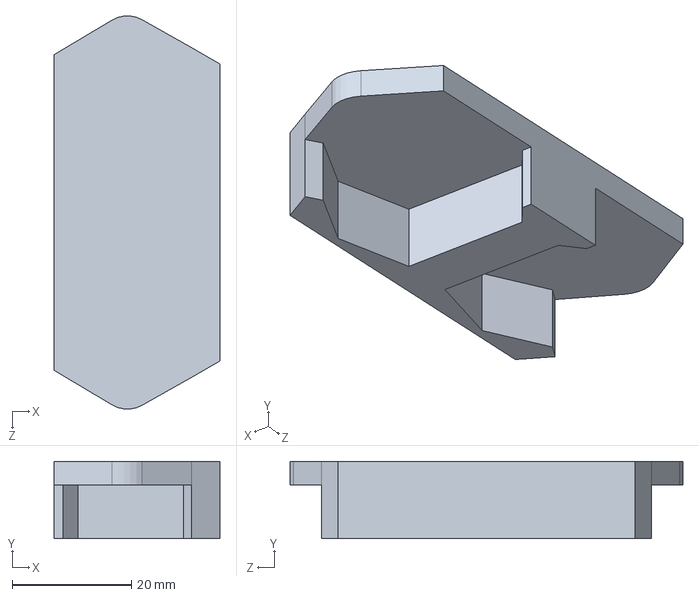
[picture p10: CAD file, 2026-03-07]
04 Solidworks/底座2.SLDPRT
27.8 x 13.0 x 66.0 mm

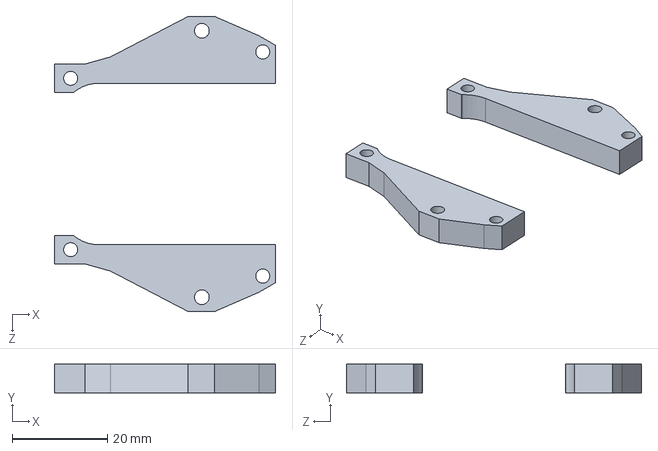
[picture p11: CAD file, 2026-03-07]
04 Solidworks/底座3.SLDPRT
46.5 x 6.00 x 62.0 mm

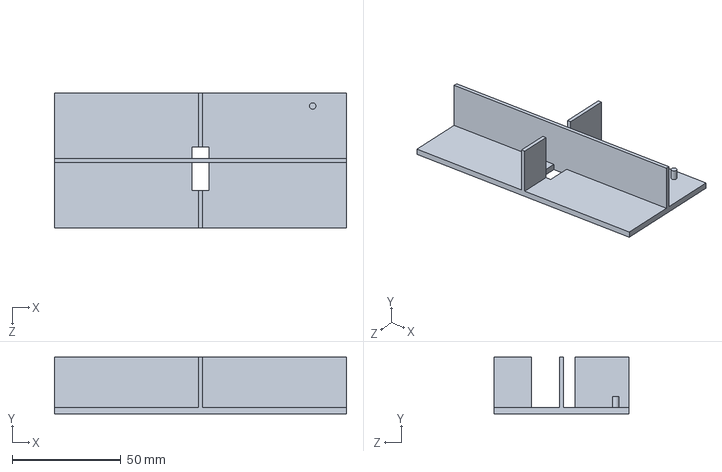
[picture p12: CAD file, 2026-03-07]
04 Solidworks/底座1.SLDPRT
134.0 x 26.0 x 62.0 mm

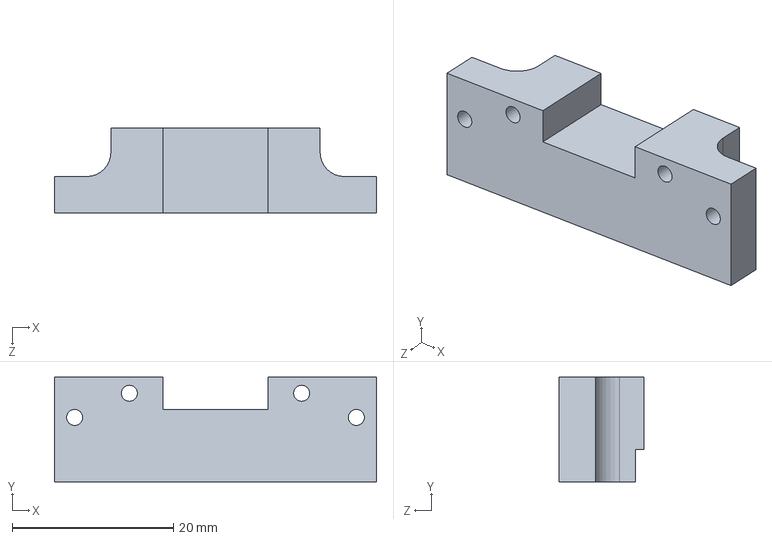
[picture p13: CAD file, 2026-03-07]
04 Solidworks/底座6.SLDPRT
40.0 x 13.0 x 10.5 mm

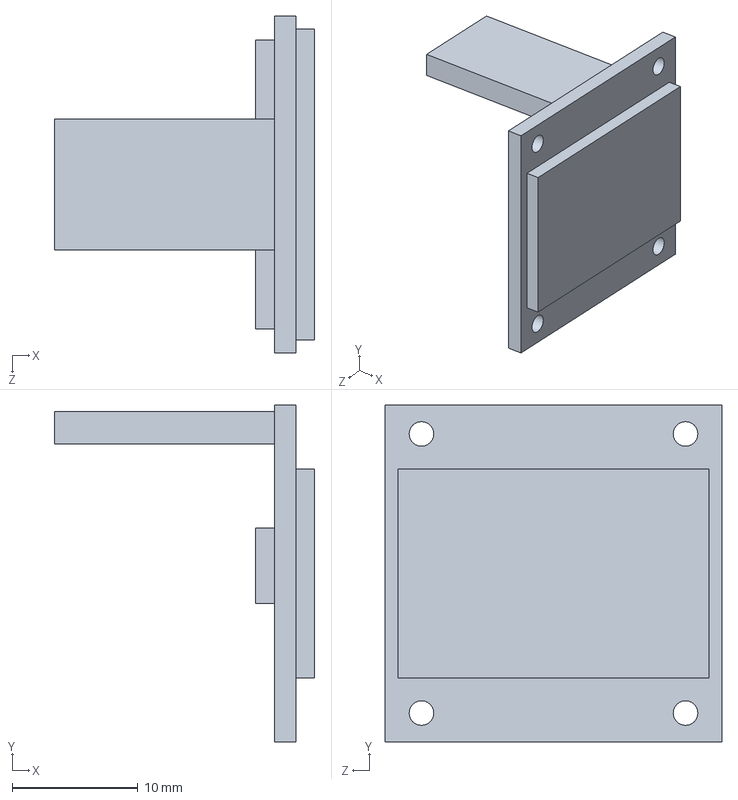
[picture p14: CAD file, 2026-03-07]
04 Solidworks/0.96寸OLED模块.SLDPRT
20.7 x 26.8 x 26.8 mm

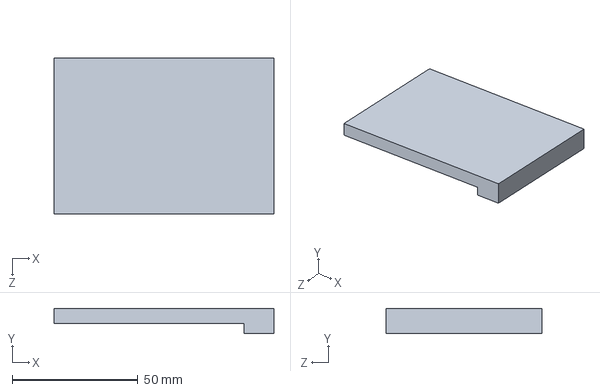
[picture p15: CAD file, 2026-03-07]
04 Solidworks/底座4.SLDPRT
87.5 x 10.0 x 62.0 mm

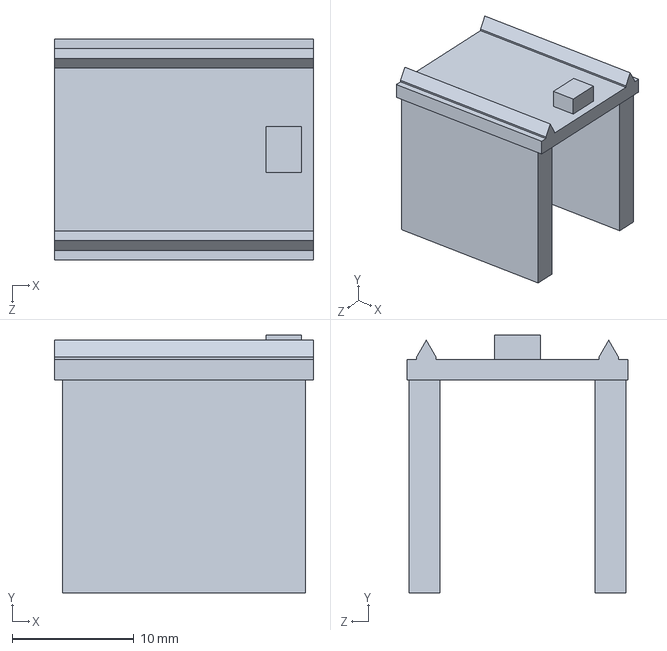
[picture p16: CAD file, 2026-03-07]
04 Solidworks/电机驱动TB6612模块.SLDPRT
21.3 x 21.2 x 18.2 mm

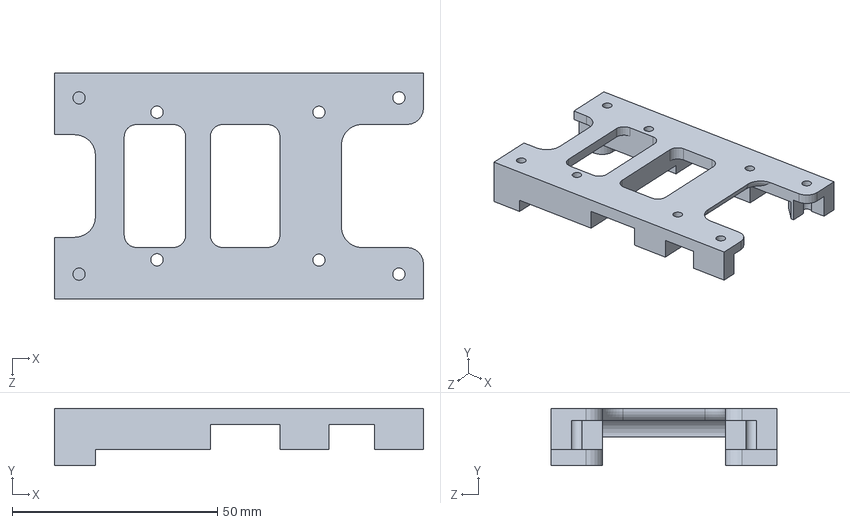
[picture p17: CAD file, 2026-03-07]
04 Solidworks/底座5.SLDPRT
90.0 x 14.0 x 55.0 mm

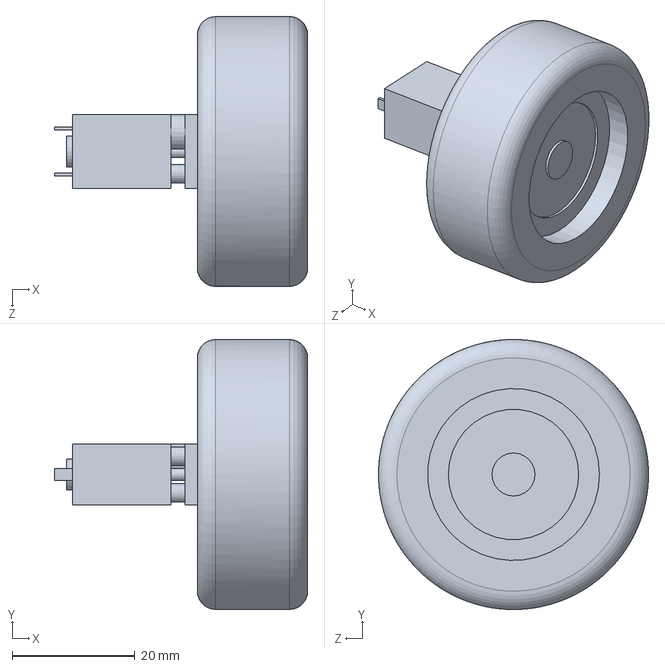
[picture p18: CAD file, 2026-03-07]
04 Solidworks/电机+轮子.SLDPRT
41.3 x 44.0 x 44.0 mm

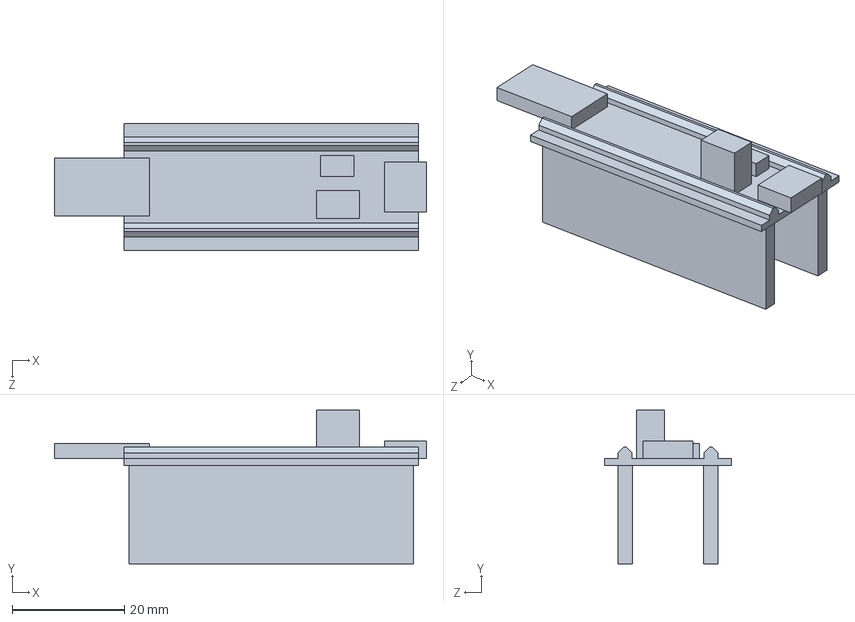
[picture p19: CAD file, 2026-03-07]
04 Solidworks/STM32F103标准最小版.SLDPRT
66.4 x 27.4 x 22.6 mm

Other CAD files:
04 Solidworks/电机+外壳.SLDASM
04 Solidworks/舵机+舵角.SLDASM
04 Solidworks/电池.SLDPRT
04 Solidworks/电子零件-电源模块.SLDPRT
04 Solidworks/电机外壳 - 后轮.SLDPRT
04 Solidworks/电机外壳.SLDPRT
04 Solidworks/舵机-舵角.SLDPRT
04 Solidworks/舵机-连杆.SLDPRT

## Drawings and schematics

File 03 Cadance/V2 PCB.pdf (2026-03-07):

# MCU STM32F103C8T6

TB6612

# MOTOR

# SERVO

# POWER

OLED | ELRS

# LED

I2C1,3V | USAERT1,5V

# GPIO

TIM3, 5V | TIM2, 5V

# VCC3V3

# VCC5V

# VCC5V

Title

Size | Document Number | Rev
Date: | Sheet | of
| 010-1010 | 1

STM32 EXP

A4

Friday, March 06, 2026 | 1 | 6
Friday, March 06, 2026 | 1 | 6
Friday, March 06, 2026 | 1 | 6

Sunday, March 01, 2026 | 2 | 6
Sunday, March 01, 2026 | 2 | 6
Sunday, March 01, 2026 | 2 | 6

MotorIC2_BIN2 MotorIC¹_BIN² MotorIC¹_BIN¹ | MotorIC¹_AIN² MotorIC¹_AIN¹ MotorIC_STBY I2C¹_SDA I2C¹_SCL | I2C²_SCL I2C²_SDA

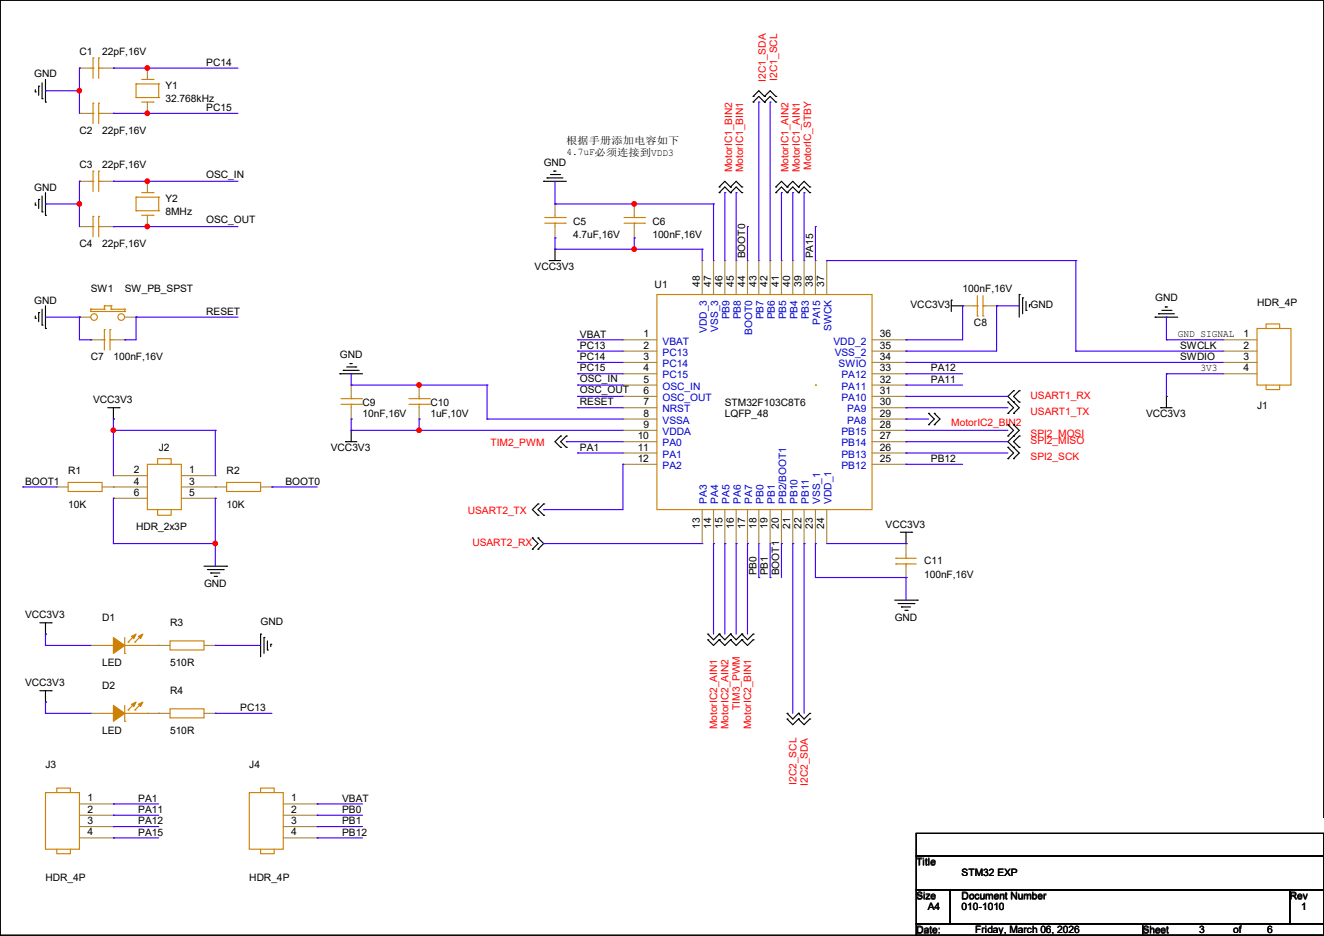
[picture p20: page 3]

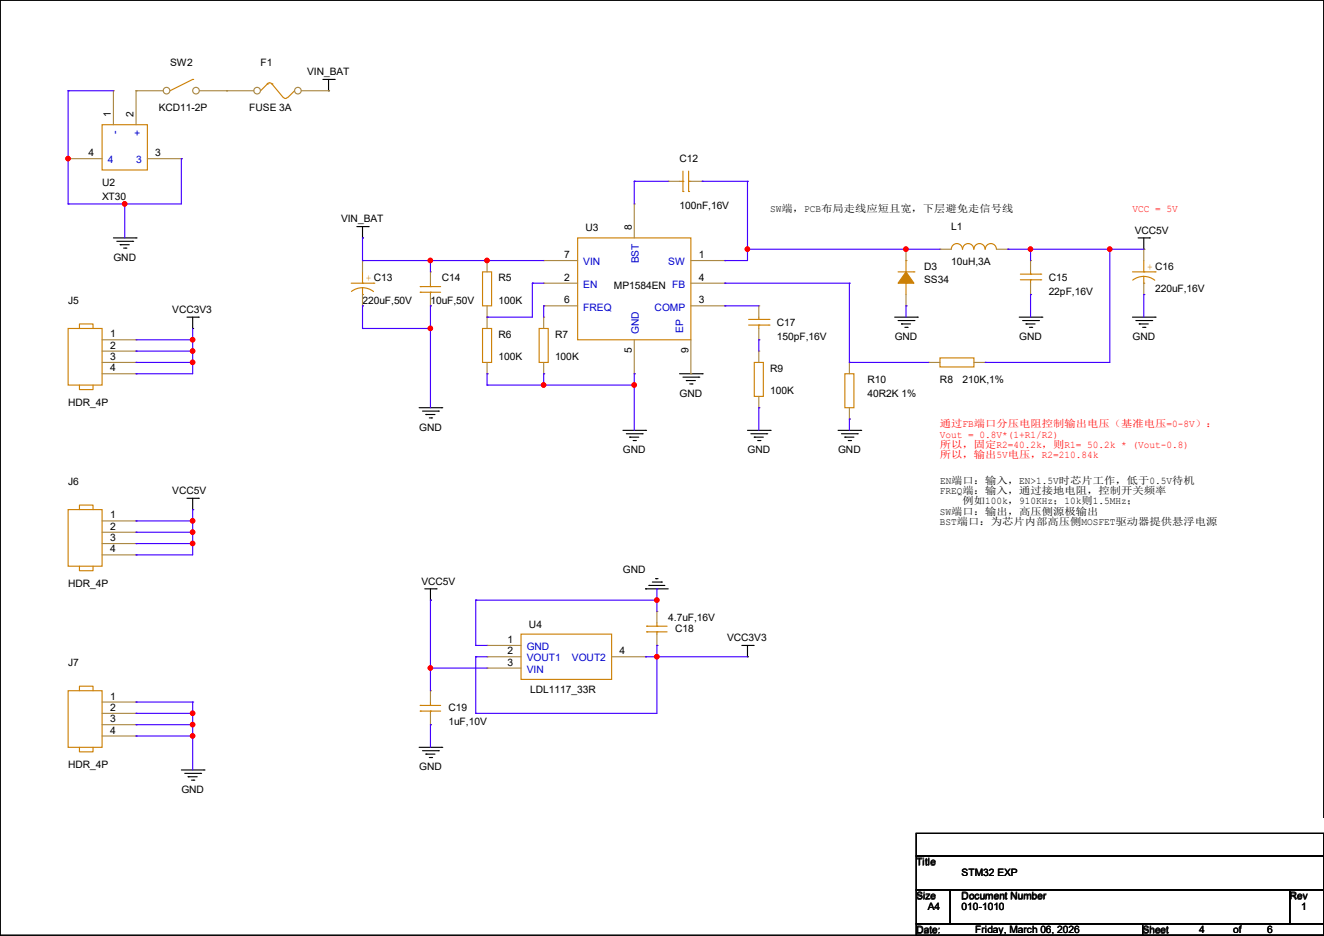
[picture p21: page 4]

EN端口：输入，EN>1.5V时芯片工作，低于0.5V待机
FREQ端：输入，通过接地电阻，控制开关频率 例如100k，910KHz；10k则1.5MHz； SW端口：输出，高压侧源极输出 BST端口：为芯片内部高压侧MOSFET驱动器提供悬浮电源

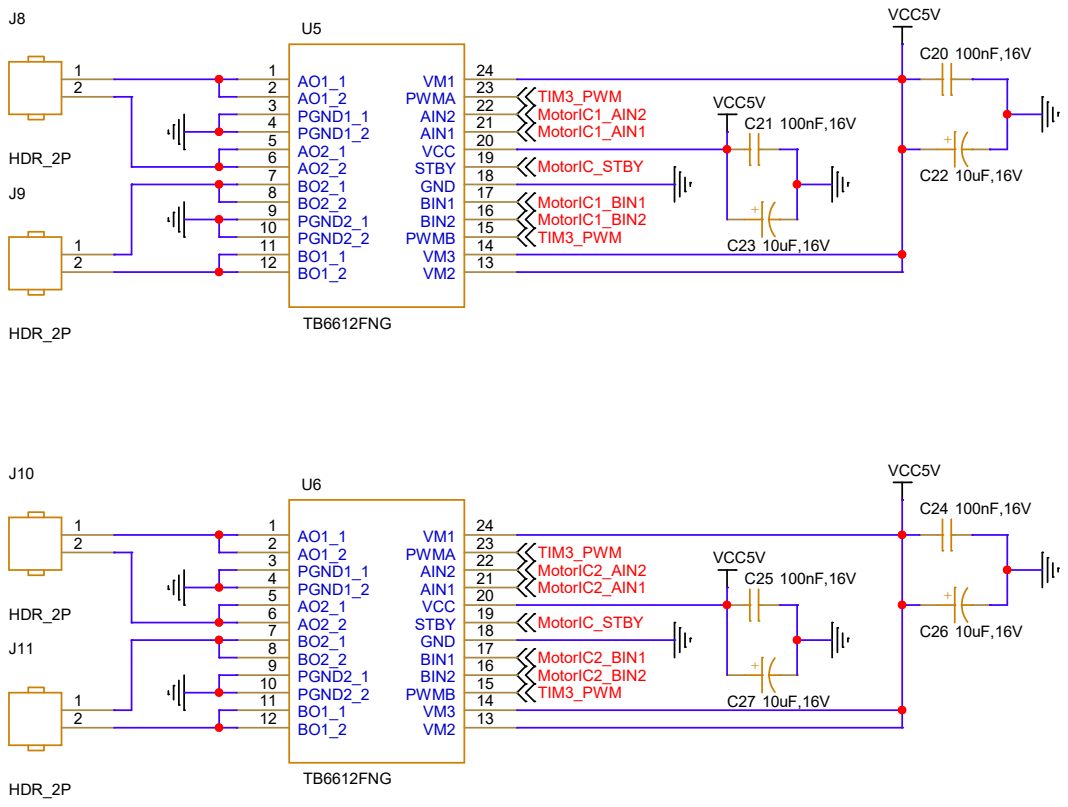
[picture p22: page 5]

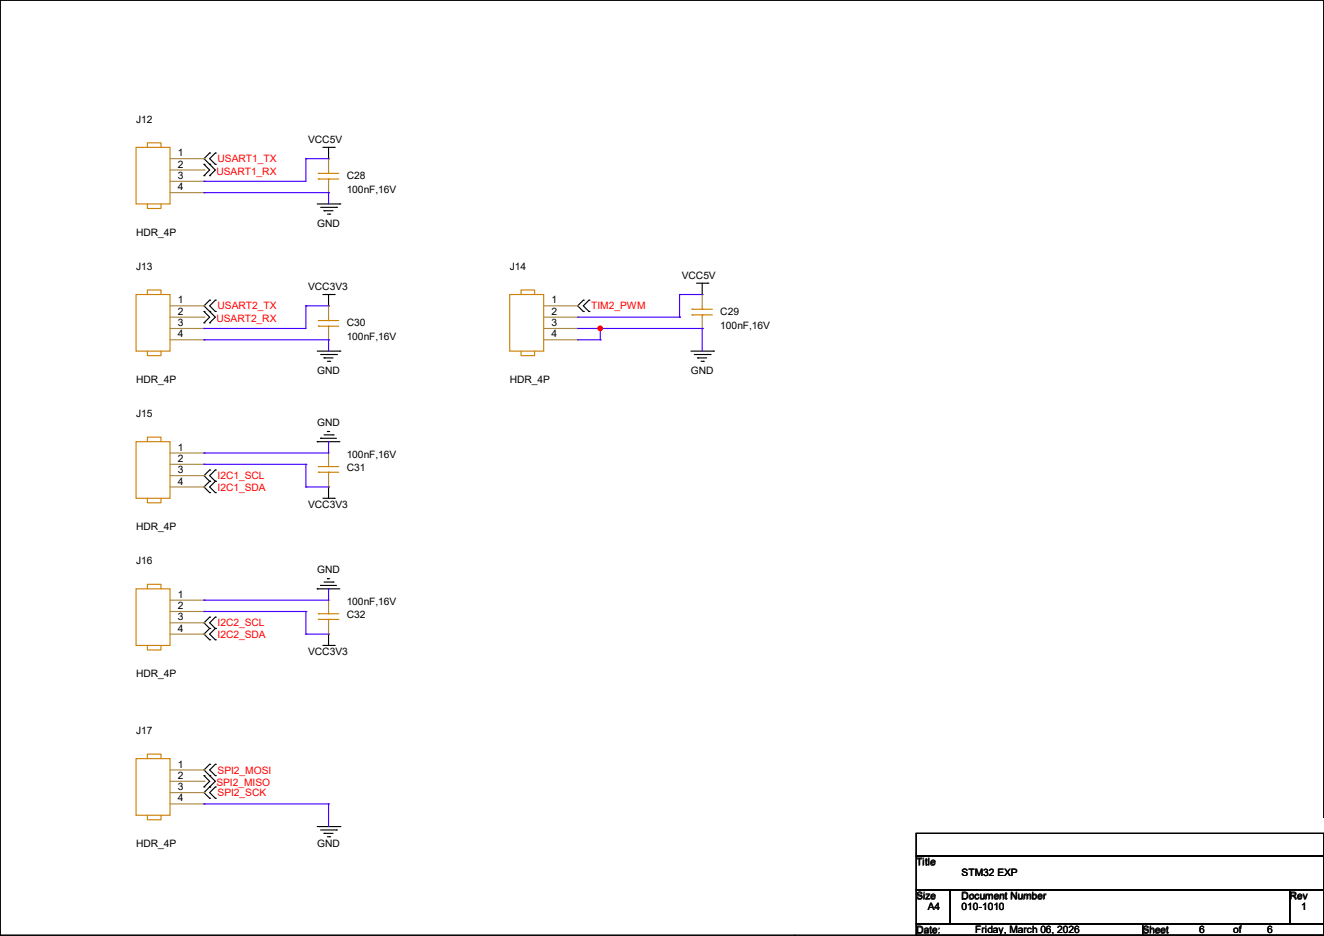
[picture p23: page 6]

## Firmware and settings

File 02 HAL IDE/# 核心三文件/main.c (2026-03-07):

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
/* Includes ------------------------------------------------------------------*/
#include "main.h"
#include "dma.h"
#include "i2c.h"
#include "spi.h"
#include "tim.h"
#include "usart.h"
#include "gpio.h"

/* USER CODE BEGIN Includes */
#include <stdio.h>
#include <string.h>
#include "para.h"
#include "sk_motor.h"
#include "oled.h"
#include "elrs.h"


/* USER CODE END Includes */


void SystemClock_Config(void);
/* USER CODE BEGIN 0 */

uint8_t DataA[26] = {0};		// 从接收接收的最原始数据
uint8_t CH[10] 	  = {0};		// 经过elrs信号解析，返回到main程序的数据，0 ~ 100

void HAL_UARTEx_RxEventCallback(UART_HandleTypeDef *huart, uint16_t Size) {
	if(huart == &huart1){
		HAL_UARTEx_ReceiveToIdle_DMA(&huart1, DataA, sizeof(DataA));
		//usart.h中声明：extern DMA_HandleTypeDef hdma_usart1_rx;
		__HAL_DMA_DISABLE_IT(&hdma_usart1_rx, DMA_IT_HT);	//关闭传输过半中断
	}
}

/* USER CODE END 0 */

/**
  * @brief  The application entry point.
  * @retval int
  */
int main(void)
{

  /* MCU Configuration--------------------------------------------------------*/

  /* Reset of all peripherals, Initializes the Flash interface and the Systick. */
  HAL_Init();

  /* Configure the system clock */
  SystemClock_Config();

  /* Initialize all configured peripherals */
  MX_GPIO_Init();
  MX_DMA_Init();
  MX_TIM3_Init();
  MX_USART2_UART_Init();
  MX_USART1_UART_Init();
  MX_I2C1_Init();
  MX_I2C2_Init();
  MX_SPI2_Init();
  MX_TIM2_Init();
  /* USER CODE BEGIN 2 */
  Motor_Init();
  Servo_Init();
  OLED_Init();

  //OLED_Test();
  OLED_ShowString(1, 1, "My Mini-Car");

  //开始接收ELRS数据
  HAL_UARTEx_ReceiveToIdle_DMA(&huart1, DataA, sizeof(DataA));
  //usart.h中声明：extern DMA_HandleTypeDef hdma_usart1_rx;
  __HAL_DMA_DISABLE_IT(&hdma_usart1_rx, DMA_IT_HT);	//关闭传输过半中断


  /* USER CODE END 2 */

  /* Infinite loop */
  /* USER CODE BEGIN WHILE */
  while (1)
  {

	  ELRS_Process(DataA, CH);	//通过DMA通道接收数据，并在循环中处理信号，结果为CH[10]，数据范围0~100
	  //设CH[2]为油门通道，CH[0]为转向通道
//	  Servo_Move(CH[0]);
//	  Motor_Move(CH[2], 30);	//起始值为30；

	  ELRS_Test(CH[0]);



    /* USER CODE END WHILE */

    /* USER CODE BEGIN 3 */
  }
  /* USER CODE END 3 */
}

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


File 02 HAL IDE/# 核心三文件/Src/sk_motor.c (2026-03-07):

/*
 * sk_motor.c
 *
 *  Created on: Jan 21, 2026
 *      Author: SAHNG
 *
 *  程序细节在头文件中秒速
 */

#include "sk_motor.h"
#include "tim.h"
#include "gpio.h"


void Servo_Init(void){
	//设计舵机角度
	//TIM2输出PWM（PA0），50Hz（设置为PRE=80，ARR=2000）
	//占空比2.5%~12.5%对应0~180度；
	//则比较器设为 50~250，对应0~180度
	__HAL_TIM_SET_COMPARE(&htim2, TIM_CHANNEL_1, SERVO_WORK_INIT+5);	//设置舵机初始角度,试验出的值

	HAL_TIM_PWM_Start(&htim2, TIM_CHANNEL_1);

	//矫正
	HAL_Delay(30);
	__HAL_TIM_SET_COMPARE(&htim2, TIM_CHANNEL_1, SERVO_WORK_INIT-5);	//设置舵机初始角度,试验出的值
	HAL_Delay(30);
	__HAL_TIM_SET_COMPARE(&htim2, TIM_CHANNEL_1, SERVO_WORK_INIT);	//设置舵机初始角度,试验出的值

	//***********************************************************************************//
	//MID=158，>MID左转（MAX=190），<MID右转(MAX=126)
	//为了避免舵机吱吱的响，可以先设一个大角度，过30ms后，再设一个小5的角度，这样就不会响了

}

void Servo_Move(uint8_t CHn){
	/* 根据输入数值，改变舵机转向。
	 * 参数：
	 * 		CHn：要求0~100，0是左转最大值，100是右转最大值
	 *
	 * 无返回值
	 * */
	CHn = 100 - CHn;	//左右转对调
	uint8_t Servo_Value = (CHn*(SERVO_WORK_MAX_L - SERVO_WORK_MAX_R) + SERVO_WORK_MAX_R*100)/100;	// 最后除以100，不然小数会被消掉
	__HAL_TIM_SET_COMPARE(&htim2, TIM_CHANNEL_1, Servo_Value);
}

void Motor_Init(void){

	//设置PWM波初始值
	__HAL_TIM_SET_COMPARE(&htim3, TIM_CHANNEL_1, MOTOR_ROTATE_INIT);	//设置比较器的初始值

	//设置IC参数
	//STBY：1=正常工作；0=待机状态
	//IN = 11 制动，01反转，10正转，00停止
	HAL_GPIO_WritePin(MotorIC_STBY_GPIO_Port, MotorIC_STBY_Pin, MOTOR_INIT_STATE);	//STBY = 0, no work

	HAL_GPIO_WritePin(MotorIC1_AIN1_GPIO_Port, MotorIC1_AIN1_Pin, GPIO_PIN_RESET);	//IC1 电机A
	HAL_GPIO_WritePin(MotorIC1_AIN2_GPIO_Port, MotorIC1_AIN2_Pin, GPIO_PIN_SET);	//IC1 电机A

	HAL_GPIO_WritePin(MotorIC1_BIN1_GPIO_Port, MotorIC1_BIN1_Pin, GPIO_PIN_SET);	//IC1 电机B
	HAL_GPIO_WritePin(MotorIC1_BIN2_GPIO_Port, MotorIC1_BIN2_Pin, GPIO_PIN_RESET);	//IC1 电机B

	HAL_GPIO_WritePin(MotorIC2_AIN1_GPIO_Port, MotorIC2_AIN1_Pin, GPIO_PIN_SET);	//IC2 电机A
	HAL_GPIO_WritePin(MotorIC2_AIN2_GPIO_Port, MotorIC2_AIN2_Pin, GPIO_PIN_RESET);	//IC2 电机A

	HAL_GPIO_WritePin(MotorIC2_BIN1_GPIO_Port, MotorIC2_BIN1_Pin, GPIO_PIN_SET);	//IC2 电机B
	HAL_GPIO_WritePin(MotorIC2_BIN2_GPIO_Port, MotorIC2_BIN2_Pin, GPIO_PIN_RESET);	//IC2 电机B


	HAL_TIM_PWM_Start(&htim3, TIM_CHANNEL_1);		// Very Very Important
}

void Motor_Move(uint8_t CHn, uint8_t Start){
	/* 根据输入值，改变油门大小
	 * 参数：
	 * 		CHn：	要求0~100，0是油门最小值，100是油门最大值
	 * 		Start:	要求0~100，是电机开始转动的起始值
	 * 无返回值
	 * */
	if(CHn > Start){
		__HAL_TIM_SET_COMPARE(&htim3, TIM_CHANNEL_1, CHn*10);	//设置比较器的值，范围0~1000
		HAL_GPIO_WritePin(MotorIC_STBY_GPIO_Port, MotorIC_STBY_Pin, GPIO_PIN_SET);
	}
	else{
		HAL_GPIO_WritePin(MotorIC_STBY_GPIO_Port, MotorIC_STBY_Pin, GPIO_PIN_RESET);
	}

}

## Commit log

2026-03-07 Rename C15051_DC-DC电源芯片_MP1584EN-LF-Z_规格书_WJ1074595.PDF to 00 Reference/C15051_DC-DC电源芯片_MP1584EN-LF-Z_规格书_WJ1074595.PDF
2026-03-07 Rename C435835_线性稳压器(LDO)_LDL1117S33R_规格书_WJ134515.PDF to 00 Reference/C435835_线性稳压器(LDO)_LDL1117S33R_规格书_WJ134515.PDF
2026-03-07 Rename C88224_有刷直流电机驱动芯片_TB6612FNG(O,C,8,EL_规格书_WJ137724.PDF to 00 Reference/C88224_有刷直流电机驱动芯片_TB6612FNG(O,C,8,EL_规格书_WJ137724.PDF
2026-03-07 Update and rename 02 HAL IDE/main.c to 02 HAL IDE/# 核心三文件/main.c
2026-03-13 删减一部分，以减小文件体积，上传招聘软件

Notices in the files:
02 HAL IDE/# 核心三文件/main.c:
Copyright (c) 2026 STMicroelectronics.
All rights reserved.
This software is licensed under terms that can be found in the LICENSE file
